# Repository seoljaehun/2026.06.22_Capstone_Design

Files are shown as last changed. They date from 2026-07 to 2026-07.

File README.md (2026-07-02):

## 2026.06.22_Capston Degine

---

# 🧤 Cross-Feedback Haptic Glove

원격 조작 및 디지털 트윈 환경을 위한 고정밀 양방향 촉각 피드백 시스템 
- 팀명: AIM (최승범, 이승우, 설재훈, 이민권)  
- 개발 기간: 2025.09 ~ 2026.06

---

# 💡 Background & Objective

원격 작업 및 디지털 트윈 환경은 시각 정보에 크게 의존하여, 실제 작업 시 필수적인 접촉감, 압력감 등의 촉각 정보 전달에 한계가 있다. 기존의 단순 진동 기반 햅틱 기술로는 물리적인 저항감이나 3차원 방향성의 다관절 반발력을 재현하기 어렵다.

이러한 문제를 해결하기 위해, 본 프로젝트는 사용자 손동작을 가상 환경에 실시간으로 동기화하고, 가상 객체와의 접촉 시 발생하는 반발력을 직관적인 물리적 저항감으로 작업자에게 다시 전달하는 '양방향 촉각 인터페이스(Cross-Feedback)'를 개발하는 것을 목표로 한다.

# ⚙️ System Architecture

**#1. Hardware Design**

총 6-DOF의 다관절 추적 프레임과 정밀 손가락 기구부를 설계하여 3D 프린팅으로 자체 제작

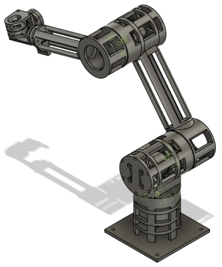
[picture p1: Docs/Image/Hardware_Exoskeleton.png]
Hardware_Exoskeleton


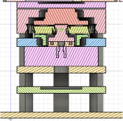
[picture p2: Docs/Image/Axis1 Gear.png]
Axis1 Gear

Axis2, 3 Gear

- **6-DOF Tracking Frame**: Base, Axis 2, Axis 3 모터와 끝단의 3축 짐벌(Gimbal Wrist) 구조를 결합하여 손목의 미세한 위치 및 회전을 추적

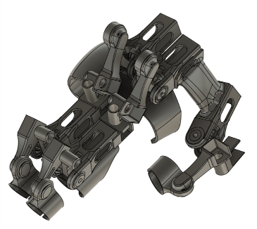
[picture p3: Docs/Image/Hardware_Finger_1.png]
Hardware_Finger_1

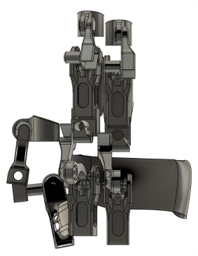
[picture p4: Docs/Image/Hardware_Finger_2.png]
Hardware_Finger_2


- **Finger Mechanism**: 검지, 중지, 엄지에 대응하는 기구부로, 2축 굽힘 운동을 위한 9-Link Mechanism과 미세한 측면 벌어짐을 측정하는 Base Splay Link(1-DOF)로 구성

**#2. Software Stack**

- **통신**: ESP32를 활용한 센서 및 모터 드라이버 간 실시간 CAN/Serial 통신 (목표 지연율 20ms 이내).
- **가상 환경**: Unity를 이용한 실시간 Hand Model 동기화 및 물리 연산.

# 🧠 Core Technology

**#1. 능동형 중력 및 마찰 보상 (Gravity & Friction Compensation)**

사용자가 기구부의 무게나 모터의 저항을 느끼지 못하도록 제어 알고리즘을 적용

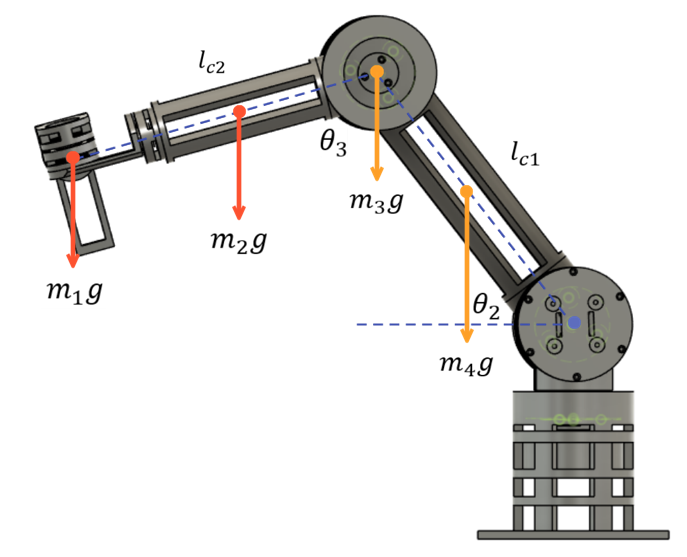
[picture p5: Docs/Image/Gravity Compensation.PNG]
Gravity Compensation


- **중력 보상**: 시스템 동역학 방정식을 기반으로, 특정 링크에 작용하는 중력 벡터를 실시간으로 계산해 피드포워드로 상쇄 토크를 인가

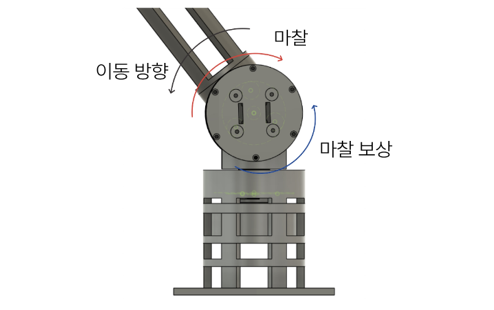
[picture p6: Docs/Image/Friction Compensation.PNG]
Friction Compensation


- **마찰 보상**: 운동 방향을 추정하여 기어박스의 정지 및 이동 마찰력을 80% 비율로 보상해 시스템 투명성을 높임

[ https://drive.google.com/file/d/1x-Lz4MTiONSaEJykd6JzzbnzPlDL91jv/view?usp=sharing ]

**#2. 실시간 Motion Tracking 및 기구학 해석**

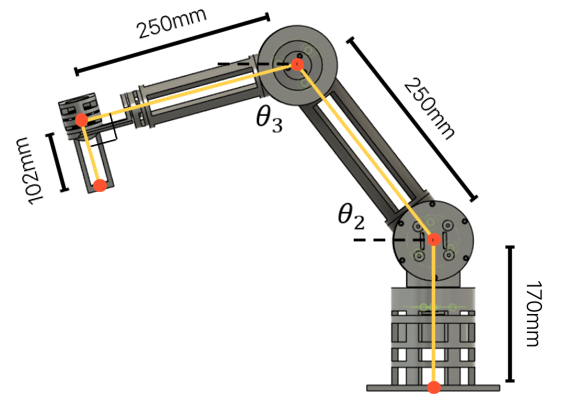
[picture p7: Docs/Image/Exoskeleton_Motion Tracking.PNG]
Exoskeleton_Motion Tracking


- **정기구학 (Forward Kinematics)**: 링크 길이(250mm)와 각 관절의 각도를 연산하여 손가락 끝점의 3차원 절대 좌표를 실시간으로 도출

[ https://drive.google.com/file/d/1qj1lQaqc14D-1eWfy3dTiHRohoCGfiwj/view?usp=sharing ]

[ https://drive.google.com/file/d/15SQRel_5A-sb6jxLStYEAN09orDJKoBw/view?usp=sharing ]

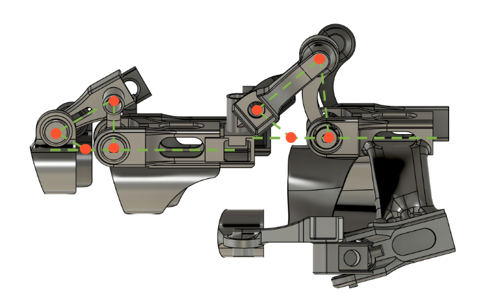
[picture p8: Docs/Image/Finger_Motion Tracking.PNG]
Finger_Motion Tracking


- **정규화 매핑**: 엔코더 센서의 raw 데이터를 0~1 비율로 정규화하여 가상 손가락의 굽힘(Curl) 수치로 완벽하게 맵핑

[ https://drive.google.com/file/d/1RPwCBb2-ctyh7ZDKhv3_87NWwyNwreAw/view?usp=sharing ]

[ https://drive.google.com/file/d/1Bs6ixnb0EOAagmnX2_hkqc2qZl57GKjI/view?usp=sharing ]

**#3. 물리적 반력 제어 (Force Feedback)**

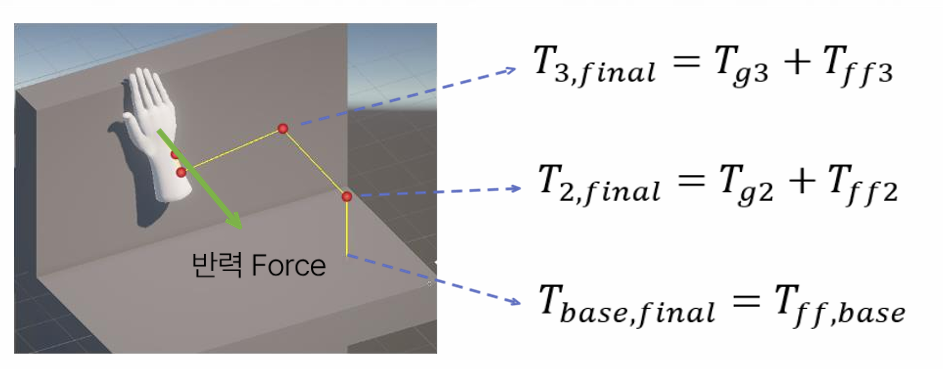
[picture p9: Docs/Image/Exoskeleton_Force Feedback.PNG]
Exoskeleton_Force Feedback


- **가상 침투 깊이 연산**: Unity 환경 내에서 손가락 끝점과 가상 객체 간의 충돌을 감지하고, 표면을 뚫고 들어간 '침투 깊이'를 실시간으로 추적
- **Jacobian 기반 토크 맵핑**: 침투 깊이와 객체의 강성(Stiffness) 계수를 바탕으로 계산된 3차원 힘 벡터($F_x, F_y, F_z$)를 자코비안 행렬($J^T$)을 이용해 각 모터의 역방향 관절 토크로 변환 및 출력

[ https://drive.google.com/file/d/1igh2boXZCQRC_Fgk3p846dIv5pikkLu7/view?usp=sharing ]

[ https://drive.google.com/file/d/1fIxESatpOFsSkA-UGyZCKZ7Otv7NtTwW/view?usp=sharing ]

[ https://drive.google.com/file/d/1ynp35kj1Q_Nx75Aqhy7c6Xc2Nchl-2s6/view?usp=sharing ]

[ https://drive.google.com/file/d/16-4rRr4cdbPdCc31YRxrtIfJoeDOTB2A/view?usp=sharing ]

[ https://drive.google.com/file/d/1gdaaGaKoBXvRHLQNCq3nRV43FlejvNWe/view?usp=sharing ]

---

# 🛠️ Troubleshooting & Limitations

- **현실적인 피드백 타협점**: 완벽한 미세 표면 질감(Texture) 재현은 하드웨어 성능상 발열 및 기구적 제약이 따른다. 따라서 조작 직관성에 가장 큰 영향을 미치는 거시적인 압력과 저항 감각 제어에 역량을 집중하여 시스템의 안정성을 확보함
- **역기전력으로 인한 모터 토크 한계:** 햅틱 피드백 구현 시 모터가 구속(Stall)되는 상황에서 역기전력 소실로 인한 과도한 발열 문제가 발생한다. 하드웨어의 손상을 방지하기 위해 시스템 전류를 제한(Current Limit)하도록 설정하였으며, 이로 인해 구현 가능한 최대 반발력에 물리적인 타협점을 두어 시스템의 안정성을 우선적으로 확보함.
- **기구 강성 한계**: PLA 3D 프린팅 프레임 특성상 고부하 반발력 인가 시 미세한 탄성 변형이 발생할 수 있으며, 이는 추후 소재 변경을 통해 개선할 예정

# 🚀 Future Work

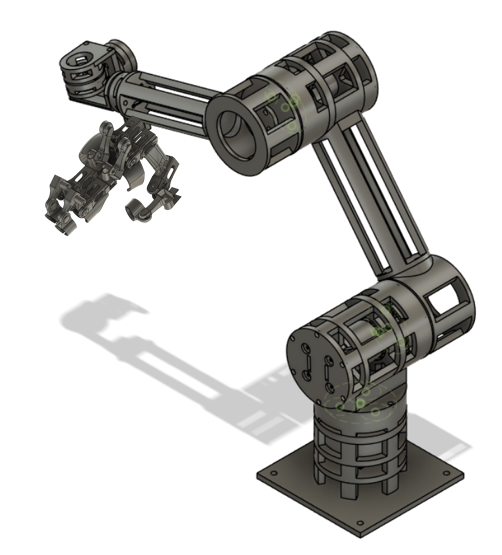
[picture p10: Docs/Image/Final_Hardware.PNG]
Final_Hardware


- **실물 로봇 연동**: 가상 시뮬레이션을 넘어, 실제 다관절 산업용 로봇 팔과의 양방향 물리적 제어 및 동기화 환경을 구축할 계획
- **AI 기반 충돌 예측 모델**: 사용자의 움직임 궤적 데이터를 딥러닝으로 학습하여, 충돌을 사전에 예측하고 대비하는 AI 모델 도입을 구상 중에 있음

---

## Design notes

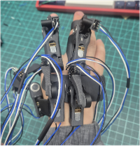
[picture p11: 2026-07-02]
Docs/Image/Hardware_Finger_Real_2.png

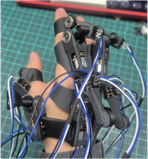
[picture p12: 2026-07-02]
Docs/Image/Hardware_Finger_Real_1.png

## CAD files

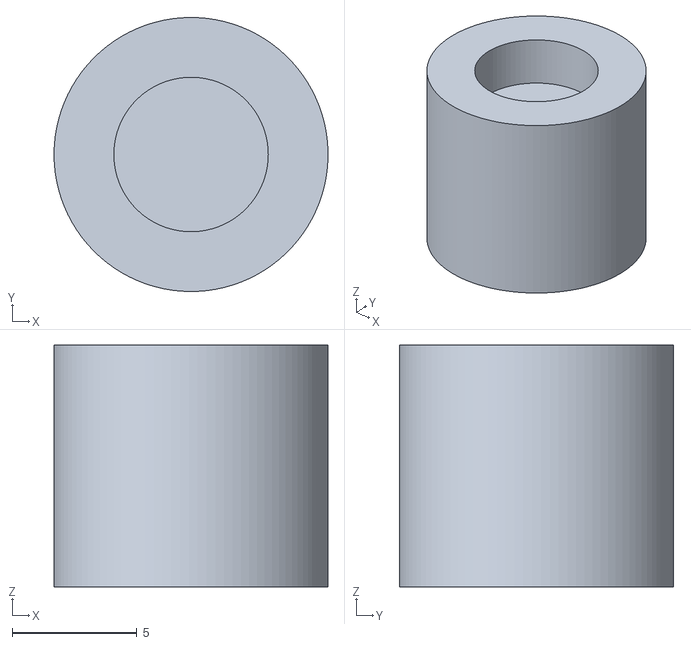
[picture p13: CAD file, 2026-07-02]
Hardware/Exoskeleton/Base_ Magnetic_Cap.stl
11.0 x 11.0 x 9.70

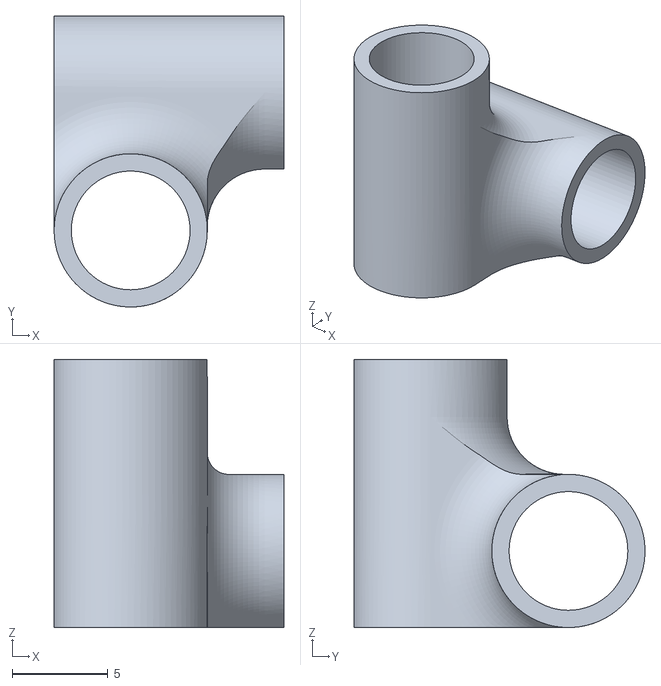
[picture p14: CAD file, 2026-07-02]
Hardware/Finger_Hand/Final_Finger/en2en_connector.stl
12.0 x 15.2 x 14.0

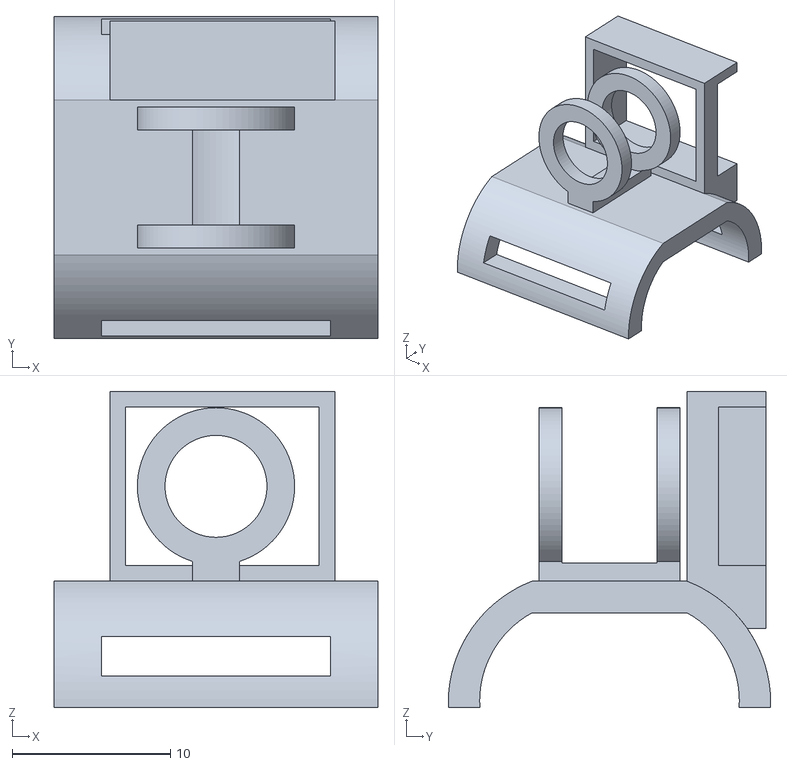
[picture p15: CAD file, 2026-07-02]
Hardware/Finger_Hand/Index/End_Pin.stl
20.5 x 20.4 x 20.0

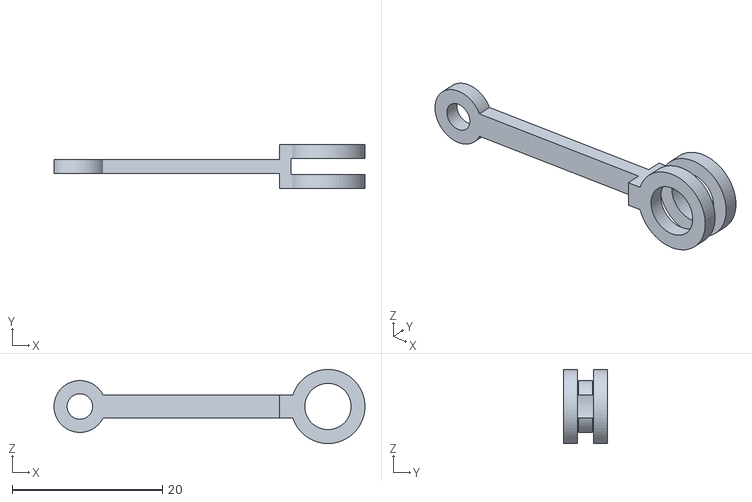
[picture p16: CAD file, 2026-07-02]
Hardware/Finger_Hand/Middle/Middle_Connect_2.stl
41.4 x 5.80 x 9.85

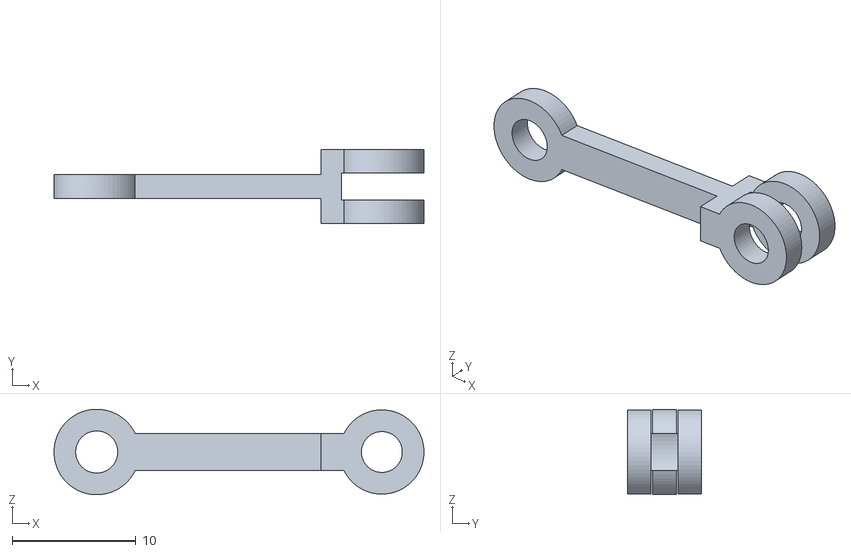
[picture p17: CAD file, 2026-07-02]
Hardware/Finger_Hand/Pincky/Middle_Connect_1.stl
29.8 x 6.00 x 6.89

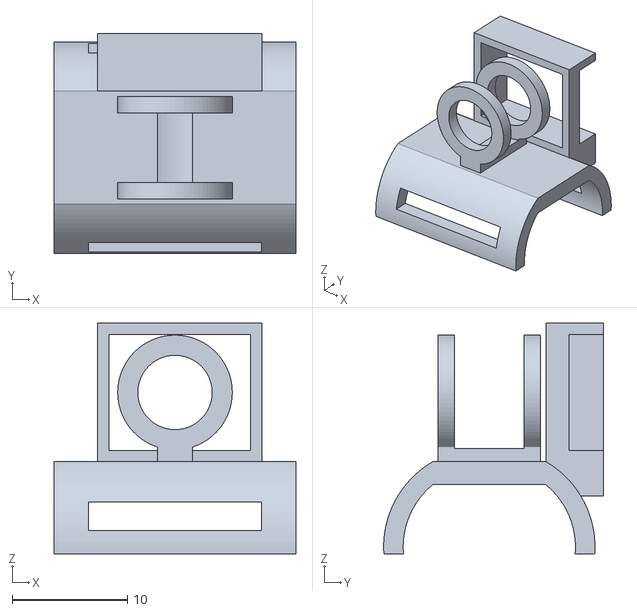
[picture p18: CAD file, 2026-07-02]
Hardware/Finger_Hand/Ring/End_Pin.stl
21.0 x 19.1 x 20.0

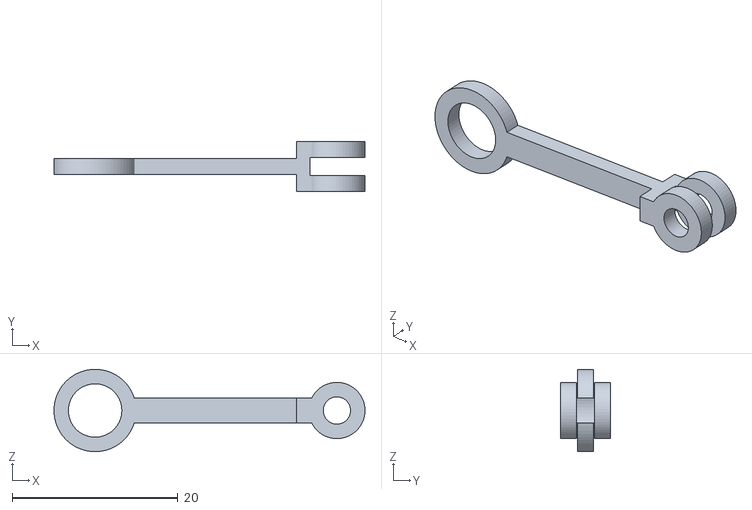
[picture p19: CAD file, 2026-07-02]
Hardware/Finger_Hand/Thumb/Middle_Connect_1.stl
37.6 x 6.00 x 9.95

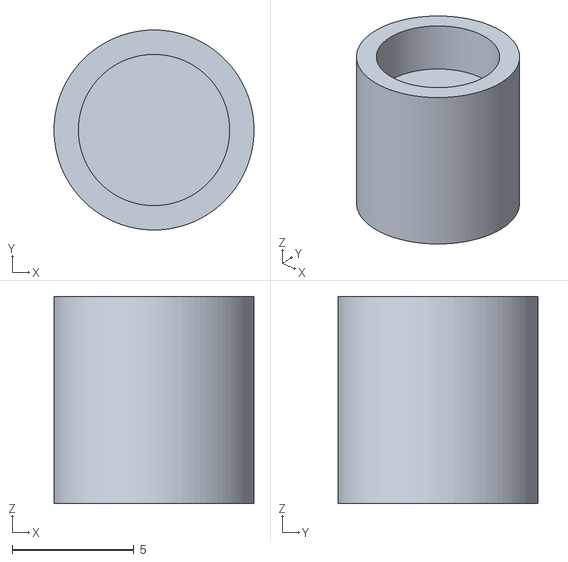
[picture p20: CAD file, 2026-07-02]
Hardware/Exoskeleton/End_ Magnetic_Cap.stl
8.20 x 8.20 x 8.50

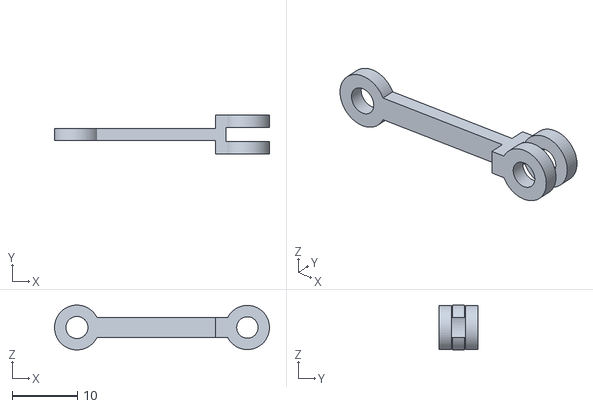
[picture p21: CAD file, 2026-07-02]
Hardware/Finger_Hand/Index/Middle_Connect_1.stl
33.1 x 6.00 x 6.90

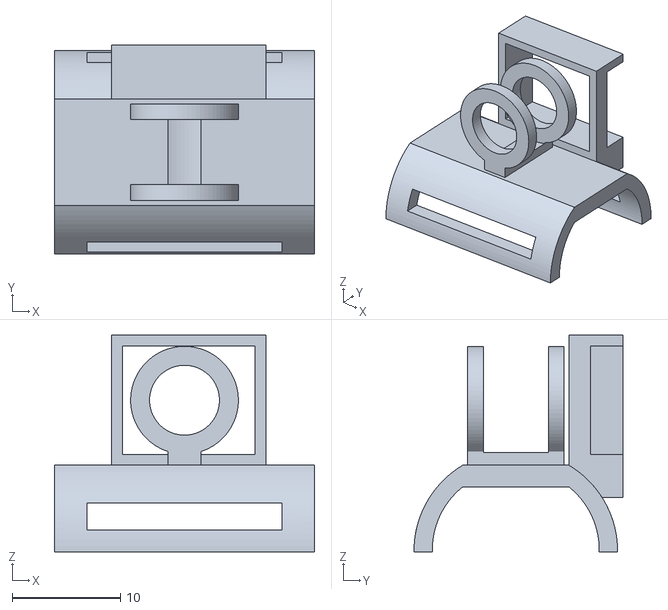
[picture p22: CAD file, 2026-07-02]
Hardware/Finger_Hand/Middle/End_Pin.stl
24.0 x 19.3 x 20.0

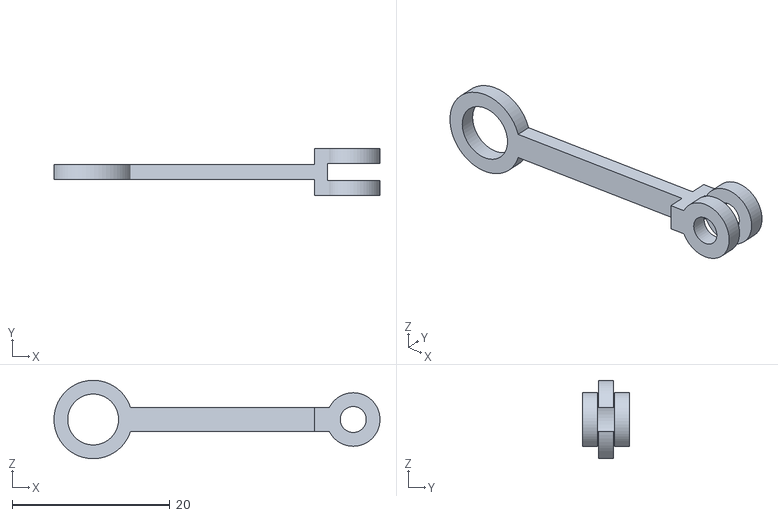
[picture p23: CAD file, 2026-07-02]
Hardware/Finger_Hand/Pincky/End_Connect_1.stl
41.4 x 6.00 x 9.95

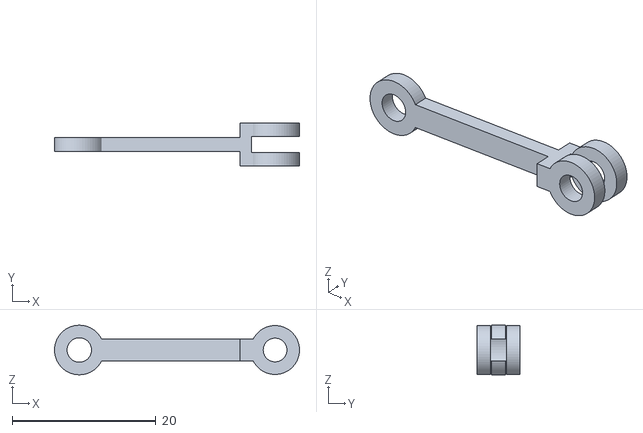
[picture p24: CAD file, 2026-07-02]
Hardware/Finger_Hand/Ring/Middle_Connect_1.stl
34.1 x 6.00 x 6.90

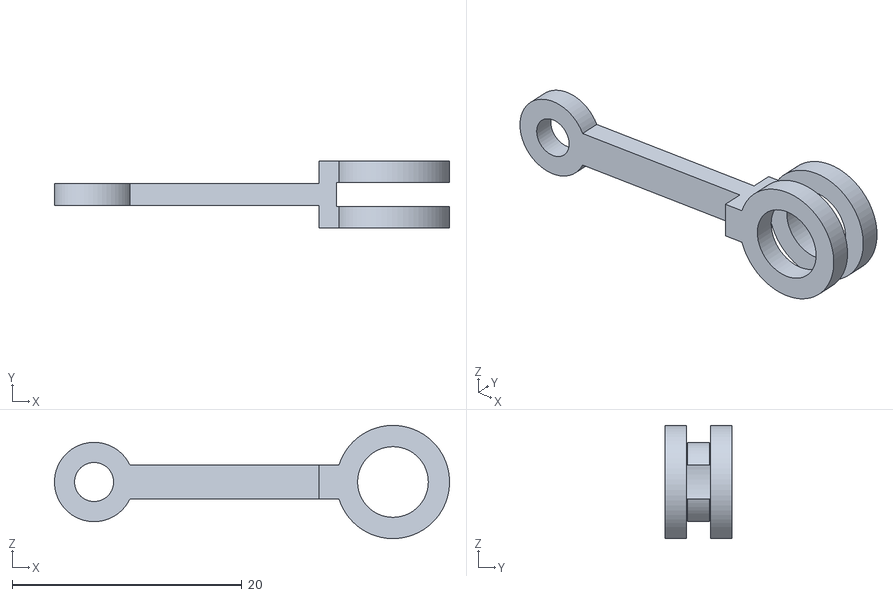
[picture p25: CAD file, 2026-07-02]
Hardware/Finger_Hand/Thumb/BackHand_Connect_2.stl
34.4 x 5.80 x 9.85

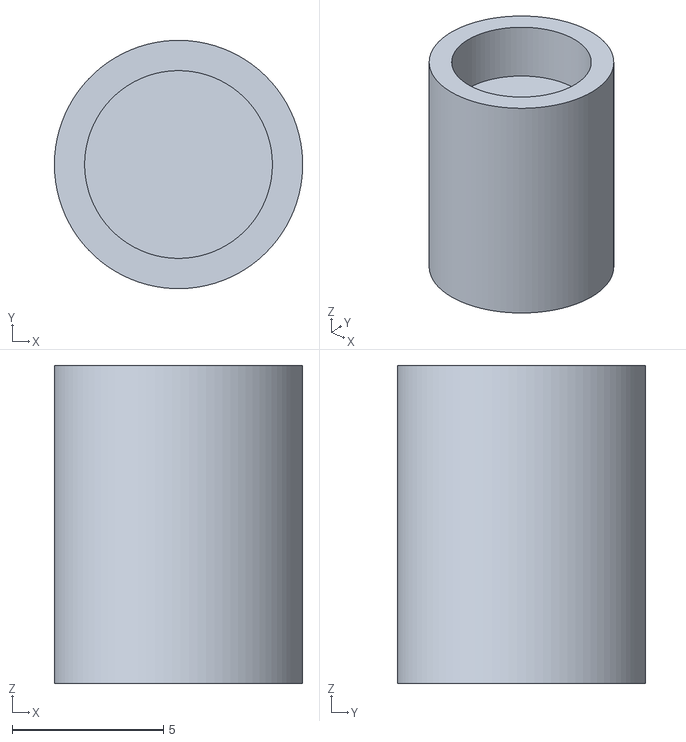
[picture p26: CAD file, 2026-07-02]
Hardware/Exoskeleton/Middle_ Magnetic_Cap.stl
8.20 x 8.20 x 10.5

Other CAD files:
Hardware/Finger_Hand/Index/Middle_Pin.stl
Hardware/Finger_Hand/Middle/End_Connect_2.stl
Hardware/Finger_Hand/Pincky/End_Connect_2.stl
Hardware/Finger_Hand/Ring/Middle_Connect_2.stl
Hardware/Exoskeleton/Base_Bearing_Outer.stl
Hardware/Exoskeleton/Base_Cap.stl
Hardware/Exoskeleton/Base_Carrier_1.stl
Hardware/Exoskeleton/Base_Carrier_2.stl
Hardware/Exoskeleton/Base_Middle_Connect_1.stl
Hardware/Exoskeleton/Base_Motor.stl
Hardware/Exoskeleton/Base_Planet_Gear.stl
Hardware/Exoskeleton/Base_Ring_Gear.stl
Hardware/Exoskeleton/Base_Sensor.stl
Hardware/Exoskeleton/Base_Sun_Gear.stl
Hardware/Exoskeleton/End_Bearing_Outer.stl
Hardware/Exoskeleton/End_Cap.stl
Hardware/Exoskeleton/End_Carrier_1.stl
Hardware/Exoskeleton/End_Carrier_2.stl
Hardware/Exoskeleton/End_Motor.stl
Hardware/Exoskeleton/End_Planet_Gear_2.stl
Hardware/Exoskeleton/End_Ring_Gear.stl
Hardware/Exoskeleton/End_Sensor.stl
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

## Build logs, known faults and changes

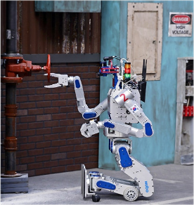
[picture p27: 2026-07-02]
Docs/Image/Problem_2.png

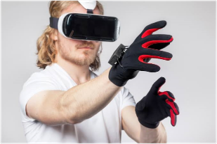
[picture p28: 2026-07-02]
Docs/Image/Problem_3.png

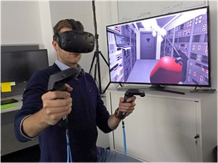
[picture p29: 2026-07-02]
Docs/Image/Problem_4.png

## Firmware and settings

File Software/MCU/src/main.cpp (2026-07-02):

#include <Arduino.h>
#include <math.h>
#include <Wire.h>
#include "driver/twai.h"

// ============================================================
//  6축 모션 트래킹 + 2축 중력 보상 + 절대각 동기화(C 패킷)
//   + 짐벌 스파이크 제거 + 저주파 필터 + 포스 피드백(base + axis2 + axis3)
//   능동축: 축1(base, node 0) / 축2(AT3520, node 2) / 축3(AT2317, node 1)
//   짐벌(수동): pitch(CH3) / yaw(CH5) / roll(CH4)  via TCA9548A
// ============================================================

// ---------- CAN (모터) ----------
#define CAN_RX_GPIO   GPIO_NUM_4
#define CAN_TX_GPIO   GPIO_NUM_5

static const uint8_t NODE1 = 0;   // base (MN7005)
static const uint8_t NODE2 = 2;   // AT3520
static const uint8_t NODE3 = 1;   // AT2317
static const float GEAR_BASE = 7.0f;
static const float GEAR = 9.61f;

// ---------- I2C (짐벌 센서) ----------
#define SDA_PIN 21
#define SCL_PIN 22
#define TCA_ADDR    0x70
#define AS5600_ADDR 0x36
#define AS5600_RAW_ANGLE 0x0C
#define CH_PITCH 3
#define CH_YAW   5
#define CH_ROLL  4

static const float ALPHA      = 0.4f;    // 짐벌 저주파 필터
static const float JUMP_LIMIT = 30.0f;   // 짐벌 스파이크 제거 (도)

// ---- 중력 모델 계수 ----
static const float G = 9.81f;
static const float TAU3_MAX = (0.14102f*0.250f + 0.07972f*0.125f) * G;
static const float M_FAR = 0.14102f + 0.07972f;
static const float R_FAR = (0.14102f*0.250f + 0.07972f*0.125f) / M_FAR;
static const float C2A = (0.08131f*0.125f + 0.53609f*0.250f + M_FAR*0.250f) * G;
static const float C2B = (M_FAR * R_FAR) * G;

// ---- 모터 토크 한계 (모터축) ----
static const float KT2 = 0.01504f, ILIM2 = 20.0f;
static const float KT3 = 0.00940f, ILIM3 = 10.0f;
static const float MAX_TRQ2 = KT2 * ILIM2;
static const float MAX_TRQ3 = KT3 * ILIM3;

// ---- 중력보상 튜닝 ----
static float SCALE2 = 0.80f;
static float SCALE3 = 0.75f;
static float SIGN2  = -1.0f;
static float SIGN3  =  1.0f;
static const float ASIGN2 = -1.0f;
static const float ASIGN3 = +1.0f;

// ---- 중력보상 슬루 ----
static const float SLEW_DTRQ = 0.010f;
static const float SLEW_WIN  = 0.005f;

// ---- 홈잉 상태 ----
static float home_base = 0.0f;
static float home2 = 0.0f;  static bool homed2 = false;
static float home3 = 0.0f;  static bool homed3 = false;

// ---- 위치 상태 ----
static float pos1 = 0.0f, vel1 = 0.0f;  static bool have1 = false;
static float pos2 = 0.0f, vel2 = 0.0f;  static bool have2 = false;
static float pos3 = 0.0f, vel3 = 0.0f;  static bool have3 = false;

// ---- 짐벌 센서 ----
static float gimPitch = 0.0f, gimYaw = 0.0f, gimRoll = 0.0f;
static float fPitch = 0.0f, fYaw = 0.0f, fRoll = 0.0f;
static bool  gimInit = false;
static bool forceActive = false;
static uint32_t gimbalGuardUntil = 0;   // 이 시각까지 짐벌 보호 (노이즈 차단)

// ---- 캘리브레이션 영점 ----
static float zeroBase = 0.0f, zeroA2 = 0.0f, zeroA3 = 0.0f;
static float zeroPitch = 0.0f, zeroYaw = 0.0f, zeroRoll = 0.0f;

// ---- 중력보상 슬루 상태 ----
static float prev_trq2 = 0.0f, prev_trq3 = 0.0f;
static uint32_t last_loop_us = 0;
static const uint32_t LOOP_US = 1000;

enum SysState { STATE_OFF, STATE_ON };
static SysState g_state = STATE_OFF;

#define CMD_GET_ENCODER_EST 0x009
#define CMD_SET_AXIS_STATE  0x007
#define CMD_SET_CTRL_MODE   0x00B
#define CMD_SET_INPUT_TRQ   0x00E
#define CMD_CLEAR_ERRORS    0x018
#define MAKE_ID(node, cmd) (((node) << 5) | (cmd))

#define ST_IDLE          1
#define ST_CLOSED_LOOP   8
#define MODE_TORQUE      1
#define MODE_PASSTHRU    1

void enterTorqueZero23();
void systemOff();

// ---------- CAN 헬퍼 ----------
void canSend(uint32_t id, uint8_t* d, uint8_t len) {
  twai_message_t m = {};
  m.identifier = id; m.extd = 0; m.rtr = 0; m.data_length_code = len;
  for (int i = 0; i < len; i++) m.data[i] = d[i];
  twai_transmit(&m, pdMS_TO_TICKS(1));
}
void setState(uint8_t n, uint32_t st){ uint8_t b[8]={0}; memcpy(b,&st,4); canSend(MAKE_ID(n,CMD_SET_AXIS_STATE),b,8);}
void setMode(uint8_t n,uint32_t cm,uint32_t im){ uint8_t b[8]={0}; memcpy(b,&cm,4); memcpy(b+4,&im,4); canSend(MAKE_ID(n,CMD_SET_CTRL_MODE),b,8);}
void setTrq(uint8_t n,float t){ uint8_t b[8]={0}; memcpy(b,&t,4); canSend(MAKE_ID(n,CMD_SET_INPUT_TRQ),b,8);}
void clrErr(uint8_t n){ uint8_t b[8]={0}; canSend(MAKE_ID(n,CMD_CLEAR_ERRORS),b,8);}

void requestEncoder(uint8_t node) {
  twai_message_t m = {};
  m.identifier = MAKE_ID(node, CMD_GET_ENCODER_EST);
  m.extd = 0; m.rtr = 1; m.data_length_code = 8;
  twai_transmit(&m, pdMS_TO_TICKS(1));
}

void pollCan() {
  twai_message_t m;
  while (twai_receive(&m, 0) == ESP_OK) {
    uint8_t node = (m.identifier >> 5) & 0x3F;
    uint8_t cmd  = m.identifier & 0x1F;
    if (cmd != CMD_GET_ENCODER_EST || m.data_length_code < 8) continue;
    if (m.rtr) continue;
    if      (node == NODE1) { memcpy(&pos1,&m.data[0],4); memcpy(&vel1,&m.data[4],4); have1=true; }
    else if (node == NODE2) { memcpy(&pos2,&m.data[0],4); memcpy(&vel2,&m.data[4],4); have2=true; }
    else if (node == NODE3) { memcpy(&pos3,&m.data[0],4); memcpy(&vel3,&m.data[4],4); have3=true; }
  }
}
void flushCan(){ twai_message_t m; while(twai_receive(&m,0)==ESP_OK); }

// ---------- base 위치추정 활성화 (warm-up) ----------
void warmUpBase() {
  Serial.println("[BASE] warm-up...");
  clrErr(NODE1); delay(50);
  setMode(NODE1, MODE_TORQUE, MODE_PASSTHRU); delay(50);
  setTrq(NODE1, 0.0f); delay(50);
  setState(NODE1, ST_CLOSED_LOOP);
  delay(500);
  setState(NODE1, ST_IDLE);
  delay(100);
  have1 = false;
  requestEncoder(NODE1);
  uint32_t t0 = micros();
  while (!have1 && (micros() - t0 < 5000)) pollCan();
  Serial.println("[BASE] warm-up done -> IDLE");
}

// ---------- I2C / 짐벌 ----------
void tcaSelect(uint8_t ch) {
  Wire.beginTransmission(TCA_ADDR);
  Wire.write(1 << ch);
  Wire.endTransmission();
}
float readAS5600(uint8_t ch) {
  tcaSelect(ch);
  Wire.beginTransmission(AS5600_ADDR);
  Wire.write(AS5600_RAW_ANGLE);
  if (Wire.endTransmission(false) != 0) {
    Serial.printf("[I2C FAIL] ch=%d (endTransmission)\n", ch);   // ★
    return -1.0f;
  }
  Wire.requestFrom(AS5600_ADDR, 2);
  if (Wire.available() < 2) {
    Serial.printf("[I2C FAIL] ch=%d (requestFrom)\n", ch);       // ★
    return -1.0f;
  }
  uint8_t hi = Wire.read();
  uint8_t lo = Wire.read();
  uint16_t raw = (((uint16_t)hi << 8) | lo) & 0x0FFF;
  return (raw / 4096.0f) * 360.0f;
}

float angDiff(float a, float b) {
  float d = a - b;
  while (d > 180.0f)  d -= 360.0f;
  while (d < -180.0f) d += 360.0f;
  return d;
}

float filterGimbal(float newVal, float prevFiltered, float alpha) {
  float diff = angDiff(newVal, prevFiltered);
  float result = prevFiltered + alpha * diff;
  while (result >= 360.0f) result -= 360.0f;
  while (result < 0.0f)    result += 360.0f;
  return result;
}

void readGimbal() {
  float p = readAS5600(CH_PITCH);
  float y = readAS5600(CH_YAW);
  float r = readAS5600(CH_ROLL);

  if (!gimInit) {
    if (p >= 0) fPitch = p;
    if (y >= 0) fYaw   = y;
    if (r >= 0) fRoll  = r;
    gimInit = true;
  } else {
    bool guarding = (millis() < gimbalGuardUntil);   // 보호 구간인가

    // 충돌 중 or 보호 구간이면 강한 필터 + 높은 점프 제한
    float alpha   = (forceActive || guarding) ? 0.1f : ALPHA;
    float jumpLim = guarding ? 3.0f : (forceActive ? 10.0f : JUMP_LIMIT);

    if (p >= 0 && fabsf(angDiff(p, fPitch)) <= jumpLim)
        fPitch = filterGimbal(p, fPitch, alpha);
    if (y >= 0 && fabsf(angDiff(y, fYaw)) <= jumpLim)
        fYaw   = filterGimbal(y, fYaw,   alpha);
    if (r >= 0 && fabsf(angDiff(r, fRoll)) <= jumpLim)
        fRoll  = filterGimbal(r, fRoll,  alpha);
  }

  gimPitch = fPitch;
  gimYaw   = fYaw;
  gimRoll  = fRoll;
}

// ---------- 축2,3 토크0 진입 ----------
void enterTorqueZero23() {
  flushCan();
  clrErr(NODE2); clrErr(NODE3); delay(50);
  setMode(NODE2, MODE_TORQUE, MODE_PASSTHRU);
  setMode(NODE3, MODE_TORQUE, MODE_PASSTHRU); delay(50);
  setTrq(NODE2, 0.0f); setTrq(NODE3, 0.0f); delay(50);
  setState(NODE2, ST_CLOSED_LOOP);
  setState(NODE3, ST_CLOSED_LOOP);

  uint32_t t0 = millis(); int s2=0, s3=0; have2=have3=false;
  while (millis()-t0 < 3000 || s2 < 50 || s3 < 50) {
    pollCan();
    setTrq(NODE2, 0.0f); setTrq(NODE3, 0.0f);
    requestEncoder(NODE1);
    if (have2){ s2++; have2=false; }
    if (have3){ s3++; have3=false; }
    delay(5);
  }
}

// ---------- 홈잉 ----------
void homeAxis2() {
  enterTorqueZero23();
  have1 = false;
  requestEncoder(NODE1);
  uint32_t t0 = micros();
  while (!have1 && (micros() - t0 < 5000)) pollCan();
  pollCan();
  home_base = pos1;
  home2 = pos2;  homed2 = true;
  Serial.printf("[HOME] axis2 @ %.5f | base @ %.5f\n", home2, home_base);
}
void homeAxis3() {
  enterTorqueZero23();
  pollCan();
  home3 = pos3;  homed3 = true;
  Serial.printf("[HOME] axis3 @ %.5f\n", home3);
}

// ---------- 팔 절대각 (deg) ----------
float baseAbsDeg() { return ((pos1 - home_base) / GEAR_BASE) * 360.0f; }
float a2AbsDeg()   { return ((pos2 - home2)     / GEAR)      * 360.0f; }
float a3AbsDeg()   { return ((pos3 - home3)     / GEAR)      * 360.0f; }

// ---------- 캘리브레이션 + C 패킷 ----------
void calibrateHand() {
  have1 = false;
  requestEncoder(NODE1);
  uint32_t t0 = micros();
  while (!have1 && (micros() - t0 < 3000)) pollCan();
  pollCan();
  readGimbal();

  zeroBase  = pos1;
  zeroA2    = pos2;
  zeroA3    = pos3;
  zeroPitch = gimPitch;
  zeroYaw   = gimYaw;
  zeroRoll  = gimRoll;

  Serial.printf("C,%.3f,%.3f,%.3f\n", baseAbsDeg(), a2AbsDeg(), a3AbsDeg());
  Serial.println("[CALIB] zeroed. C-packet sent.");
}

// ---------- 중력보상 각도 ----------
float phi2() { return ASIGN2 * ((pos2 - home2) / GEAR) * 2.0f * PI; }
float phi3() {
  float rel3 = ASIGN3 * ((pos3 - home3) / GEAR) * 2.0f * PI;
  return phi2() + rel3;
}

// ============================================================
//  포스 피드백 — FK + 자코비안 + 분배
// ============================================================
static const float L2 = 0.25f;
static const float L3 = 0.25f;

float q1rad() { return baseAbsDeg() * (float)PI / 180.0f; }

void fk(float q1, float q2, float q23, float out[3]) {
  float r = L2 * cosf(q2) + L3 * cosf(q23);
  float h = L2 * sinf(q2) + L3 * sinf(q23);
  out[0] = r * cosf(q1);
  out[1] = r * sinf(q1);
  out[2] = h;
}

void computeJacobian(float q1, float q2, float q3rel, float J[3][3]) {
  const float d = 0.001f;
  float pp[3], pm[3];
  fk(q1 + d, q2, q2 + q3rel, pp);
  fk(q1 - d, q2, q2 + q3rel, pm);
  for (int i = 0; i < 3; i++) J[i][0] = (pp[i] - pm[i]) / (2*d);
  fk(q1, q2 + d, (q2 + d) + q3rel, pp);
  fk(q1, q2 - d, (q2 - d) + q3rel, pm);
  for (int i = 0; i < 3; i++) J[i][1] = (pp[i] - pm[i]) / (2*d);
  fk(q1, q2, q2 + (q3rel + d), pp);
  fk(q1, q2, q2 + (q3rel - d), pm);
  for (int i = 0; i < 3; i++) J[i][2] = (pp[i] - pm[i]) / (2*d);
}

void jacobianTransposeForce(float J[3][3], float F[3], float tau[3]) {
  for (int j = 0; j < 3; j++)
    tau[j] = J[0][j]*F[0] + J[1][j]*F[1] + J[2][j]*F[2];
}

// ---- 관절축 토크 한계 ----
static const float TAU_LIM_BASE = 0.0719f * 10.0f * GEAR_BASE;
static const float TAU_LIM_A2   = 0.01504f * 20.0f * GEAR;
static const float TAU_LIM_A3   = 0.00940f * 12.0f * GEAR;

// ---- 포스 피드백 상태 ----
static float testF[3] = {0.0f, 0.0f, 0.0f};
static float ff_prev[3] = {0,0,0};
static const float FF_SLEW = 0.05f;
static float FF_DAMP_BASE = 0.0f;          // base 속도 감쇠 게인
static float velFiltered1 = 0.0f;
static const float VEL_ALPHA = 0.2f;
static const float BASE_ENTER_TRQ = 0.755f;  // 진입 임계 (1.5A 상당)
static const float BASE_EXIT_TRQ  = 0.252f;  // 이탈 임계 (0.5A 상당)
static uint32_t lastStrongF = 0;

static float ff_torque2 = 0.0f;   // axis2 포스피드백 토크 (모터축, 전역)
static float ff_torque3 = 0.0f;   // axis3 포스피드백 토크 (모터축, 전역)

float distributeTorque(float tau[3], float tau_out[3]) {
  float lim[3] = { TAU_LIM_BASE, TAU_LIM_A2, TAU_LIM_A3 };
  float s = 1.0f;
  for (int i = 0; i < 3; i++) {
    if (fabsf(tau[i]) > 1e-9f) {
      float ratio = lim[i] / fabsf(tau[i]);
      if (ratio < s) s = ratio;
    }
  }
  for (int i = 0; i < 3; i++) tau_out[i] = tau[i] * s;
  return s;
}

static bool baseClosedLoop = false;

void baseEnterClosedLoop() {
  if (baseClosedLoop) return;
  clrErr(NODE1);
  setMode(NODE1, MODE_TORQUE, MODE_PASSTHRU);
  setTrq(NODE1, 0.0f);
  setState(NODE1, ST_CLOSED_LOOP);
  baseClosedLoop = true;
  Serial.println("[BASE] -> CLOSED_LOOP");
}

void baseExitClosedLoop() {
  if (!baseClosedLoop) return;

  float t = ff_prev[0];
  int steps = 20;
  for (int i = steps; i >= 0; i--) {
    setTrq(NODE1, t * (float)i / steps);
    delayMicroseconds(500);
  }
  setTrq(NODE1, 0.0f);
  setState(NODE1, ST_IDLE);
  baseClosedLoop = false;
  ff_prev[0] = 0;

  gimbalGuardUntil = millis() + 500;   // 0.5초간 짐벌 보호
  Serial.println("[BASE] -> IDLE (ramped + gimbal guard)");
}

// ---- 포스 피드백 (base 인가 + axis2,3 토크 계산) ----
void applyForceFeedback() {
  float q1=q1rad(), q2=phi2(), q23=phi3(), q3rel=q23-q2;
  float J[3][3]; computeJacobian(q1, q2, q3rel, J);
  float tau[3]; jacobianTransposeForce(J, testF, tau);

  float tau_out[3];
  distributeTorque(tau, tau_out);

  // axis2,3 포스피드백 토크 계산 (loop에서 중력보상과 합산)
  ff_torque2 = -SIGN2 * tau_out[1] / GEAR;
  ff_torque3 = -SIGN3 * tau_out[2] / GEAR;

  // ---- base 진입/이탈 히스테리시스 (토크 기준) ----
  float baseTrqMag = fabsf(tau_out[0]);
  if (!baseClosedLoop && baseTrqMag > BASE_ENTER_TRQ) {
    baseEnterClosedLoop();
    ff_prev[0] = 0;
  } else if (baseClosedLoop && baseTrqMag < BASE_EXIT_TRQ) {
    baseExitClosedLoop();
    ff_prev[0] = 0;
  }

  if (!baseClosedLoop) return;   // base IDLE이면 base 토크 안 냄 (drr 차단)

  float mBase = tau_out[0] / GEAR_BASE;

  // base 속도 감쇠 (필터된 실시간 속도)
  velFiltered1 += VEL_ALPHA * (vel1 - velFiltered1);
  mBase += -FF_DAMP_BASE * velFiltered1;

  // 슬루 리미터
  float d = mBase - ff_prev[0];
  if (d >  FF_SLEW) d =  FF_SLEW;
  if (d < -FF_SLEW) d = -FF_SLEW;
  mBase = ff_prev[0] + d;
  ff_prev[0] = mBase;

  setTrq(NODE1, mBase);
}

// ---------- Unity P 패킷 전송 ----------
float wrap180(float deg) {
  while (deg > 180.0f)  deg -= 360.0f;
  while (deg < -180.0f) deg += 360.0f;
  return deg;
}

void sendToUnity() {
  float baseDeg = ((pos1 - zeroBase) / GEAR_BASE) * 360.0f;
  float a2Deg   = ((pos2 - zeroA2)   / GEAR)      * 360.0f;
  float a3Deg   = ((pos3 - zeroA3)   / GEAR)      * 360.0f;
  float pDeg = wrap180(gimPitch - zeroPitch);
  float yDeg = wrap180(gimYaw   - zeroYaw);
  float rDeg = wrap180(gimRoll  - zeroRoll);
  Serial.printf("P,%.3f,%.3f,%.3f,%.3f,%.3f,%.3f\n",
                baseDeg, a2Deg, a3Deg, pDeg, yDeg, rDeg);
}

// ---------- 시스템 ON/OFF ----------
void systemOff() {
  setTrq(NODE2, 0.0f); setTrq(NODE3, 0.0f);
  delay(10);
  setState(NODE1, ST_IDLE);
  setState(NODE2, ST_IDLE);
  setState(NODE3, ST_IDLE);
  prev_trq2 = prev_trq3 = 0.0f;
  baseClosedLoop = false;
  ff_torque2 = 0.0f;
  ff_torque3 = 0.0f;
  g_state = STATE_OFF;
  Serial.println("[SYS] OFF.");
}

void systemOn() {
  if (!homed2 || !homed3) {
    Serial.println("[SYS] not homed! (press h and j)");
    return;
  }
  clrErr(NODE2); clrErr(NODE3); delay(20);
  setMode(NODE2, MODE_TORQUE, MODE_PASSTHRU);
  setMode(NODE3, MODE_TORQUE, MODE_PASSTHRU); delay(20);
  setState(NODE2, ST_CLOSED_LOOP);
  setState(NODE3, ST_CLOSED_LOOP); delay(20);
  prev_trq2 = prev_trq3 = 0.0f;
  last_loop_us = micros();
  g_state = STATE_ON;
  Serial.println("[SYS] ON.");
}

// ---------- F 패킷 파싱 ----------
void parseForcePacket(const String& line) {
  int c1 = line.indexOf(',');
  int c2 = line.indexOf(',', c1+1);
  int c3 = line.indexOf(',', c2+1);
  if (c1<0 || c2<0 || c3<0) return;

  testF[0] = line.substring(c1+1, c2).toFloat();
  testF[1] = line.substring(c2+1, c3).toFloat();
  testF[2] = line.substring(c3+1).toFloat();

  float mag = sqrtf(testF[0]*testF[0] + testF[1]*testF[1] + testF[2]*testF[2]);
  if (mag > 0.5f) {
    forceActive = true;
    lastStrongF = millis();
  }
}

// ---------- 시리얼 ----------
void handleSerial() {
  static String buf = "";
  while (Serial.available()) {
    char c = Serial.read();
    if (c == '\n' || c == '\r') {
      if (buf.length() == 0) return;
      if (buf.startsWith("F,")) {
        parseForcePacket(buf);
      } else if (buf.length() == 1) {
        char k = buf[0];
        if      (k == 'q') { if (g_state==STATE_OFF) systemOn(); }
        else if (k == 'w') systemOff();
        else if (k == 'h') homeAxis2();
        else if (k == 'j') homeAxis3();
        else if (k == 'k') calibrateHand();
      }
      buf = "";
    } else {
      buf += c;
      if (buf.length() > 64) buf = "";
    }
  }
}

void setup() {
  Serial.begin(115200);
  delay(500);
  Serial.println("\n=== 6-Axis Tracking + Gravity + Force Feedback ===");

  twai_general_config_t g = TWAI_GENERAL_CONFIG_DEFAULT(CAN_TX_GPIO, CAN_RX_GPIO, TWAI_MODE_NORMAL);
  twai_timing_config_t  t = TWAI_TIMING_CONFIG_250KBITS();
  twai_filter_config_t  f = TWAI_FILTER_CONFIG_ACCEPT_ALL();
  if (twai_driver_install(&g,&t,&f)!=ESP_OK){ Serial.println("[FATAL] TWAI install"); while(1)delay(100);}
  if (twai_start()!=ESP_OK){ Serial.println("[FATAL] TWAI start"); while(1)delay(100);}
  Serial.println("[INIT] CAN up @250kbps");

  Wire.begin(SDA_PIN, SCL_PIN);
  Wire.setClock(400000);
  Wire.beginTransmission(TCA_ADDR);
  if (Wire.endTransmission()==0) Serial.println("[INIT] TCA9548A OK");
  else Serial.println("[WARN] TCA9548A not found");

  warmUpBase();

  Serial.println("Keys: q=ON w=OFF h=home2 j=home3 k=calib");
  Serial.println("Step: h -> j -> q -> (palm-down) -> k");
}

void loop() {
  handleSerial();

  static uint32_t last_req = 0;
  if (millis() - last_req >= 20) {
    last_req = millis();
    requestEncoder(NODE1);
  }
  pollCan();

  if (g_state != STATE_ON) { delay(2); return; }

  uint32_t now = micros();
  if (now - last_loop_us < LOOP_US) return;
  float dt = (now - last_loop_us) * 1e-6f;
  last_loop_us = now;

  readGimbal();

  // 충돌 타임아웃 종료
  if (forceActive && (millis() - lastStrongF > 300)) {
    forceActive = false;
    testF[0]=testF[1]=testF[2]=0;
    setTrq(NODE1,0);
    ff_torque2 = 0.0f;
    ff_torque3 = 0.0f;
    baseExitClosedLoop();
  }

  // --- 2·3번 중력 보상 (항상) + axis2,3 포스피드백 합산 ---
  {
    float p2 = phi2();
    float p3 = phi3();
    float tau3_link = TAU3_MAX * cosf(p3);
    float tau2_link = C2A * cosf(p2) + C2B * cosf(p3);

    float trq3 = SIGN3 * SCALE3 * tau3_link / GEAR;
    float trq2 = SIGN2 * SCALE2 * tau2_link / GEAR;

    if (trq3 >  MAX_TRQ3) trq3 =  MAX_TRQ3;  if (trq3 < -MAX_TRQ3) trq3 = -MAX_TRQ3;
    if (trq2 >  MAX_TRQ2) trq2 =  MAX_TRQ2;  if (trq2 < -MAX_TRQ2) trq2 = -MAX_TRQ2;

    float slew = SLEW_DTRQ * (dt / SLEW_WIN);
    float d3 = trq3 - prev_trq3; if (d3>slew) d3=slew; if (d3<-slew) d3=-slew;
    float d2 = trq2 - prev_trq2; if (d2>slew) d2=slew; if (d2<-slew) d2=-slew;
    trq3 = prev_trq3 + d3;  prev_trq3 = trq3;
    trq2 = prev_trq2 + d2;  prev_trq2 = trq2;

    // axis2,3: 중력보상 + 포스피드백 합산
    float trq2_final = trq2 + (forceActive ? ff_torque2 : 0.0f);
    float trq3_final = trq3 + (forceActive ? ff_torque3 : 0.0f);
    if (trq2_final >  MAX_TRQ2) trq2_final =  MAX_TRQ2;
    if (trq2_final < -MAX_TRQ2) trq2_final = -MAX_TRQ2;
    if (trq3_final >  MAX_TRQ3) trq3_final =  MAX_TRQ3;
    if (trq3_final < -MAX_TRQ3) trq3_final = -MAX_TRQ3;

    setTrq(NODE3, trq3_final);   // 합산값 인가
    setTrq(NODE2, trq2_final);   // 합산값 인가
  }

  // --- base 포스 피드백 (충돌 중) ---
  if (forceActive) applyForceFeedback();

  // --- Unity 전송 (50Hz) ---
  static uint32_t last_tx = 0;
  if (millis() - last_tx >= 20) {
    last_tx = millis();
    sendToUnity();
  }
}
